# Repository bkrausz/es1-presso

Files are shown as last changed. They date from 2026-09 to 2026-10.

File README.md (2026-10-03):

# Presso

Gravimetric shot control for the **Fellow Espresso Series 1** — without opening the machine.

A small servo sits on top of the Series 1 and taps the espresso key. An ESP32 running
[ESPHome](https://esphome.io) talks to an **Acaia Lunar** over Bluetooth, watches the weight,
and taps the key again when the shot hits your target. It learns the drip offset after each
shot, notices shots you start by hand, and everything is exposed to Home Assistant.

The Series 1 has no scale integration of its own (as of firmware 2.3.x). This gets you
stop-at-weight today, for about $60 in parts, with zero warranty exposure — the mount clamps
to a lip on the case and lifts off in a second.

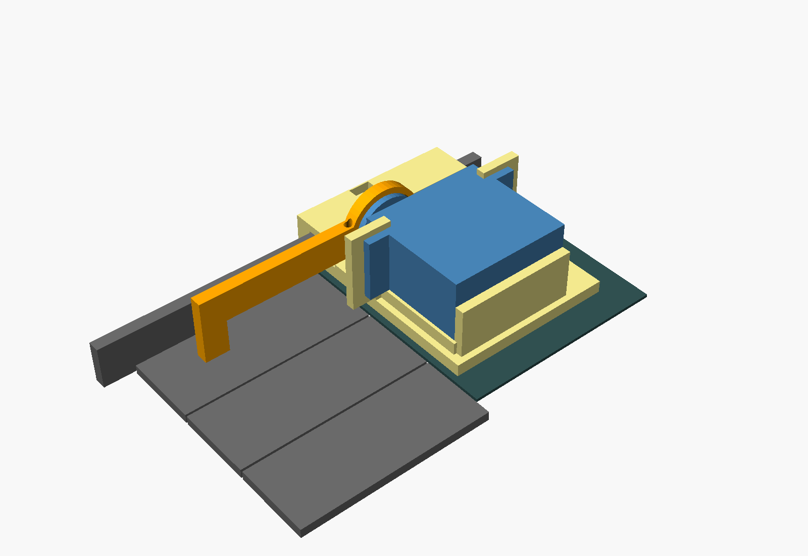
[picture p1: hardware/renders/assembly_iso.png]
Presso mount rendered on the Series 1's key cluster


> **Built with Claude.** The mount, firmware, wiring, and most of this README were designed and
> written by [Claude](https://claude.ai) (Anthropic) in conversation with Brian, who did the
> measuring, soldering, printing, and testing. The Acaia BLE protocol handling is ported from
> Tate Mazer's [AcaiaArduinoBLE / shotStopper](https://github.com/tatemazer/AcaiaArduinoBLE) —
> go star that project.

## How it works

1. You put the cup on the scale (Lunar auto-tare handles zeroing) and press **Pull shot** —
   in Home Assistant or with the button on the Atom.
2. Presso tares, starts the scale timer, and taps the espresso key.
3. It watches weight and flow rate. When `weight + flow × latency ≥ target − offset`, it taps
   the key again. It only ever presses while coffee is still flowing: if the machine ends the shot
   on its own (volumetric target, or you pressed the key), Presso stands down rather than pressing
   into a stopped machine — which would start a *new* shot. "Stopped" only counts once coffee
   has started arriving, so long pre-infusion with a dry cup is fine.
4. Three seconds after the stop it reads the settled weight and nudges the offset by the error,
   so the second or third shot lands on target.

Start the shot by hand instead and Presso notices the weight climbing and takes over the stop.

There's also a bare **Press key** button, which a Home Assistant automation uses to wake the
machine to warm up — guarded by a power-monitoring smart plug so it only presses when the machine
is actually asleep.

## Parts

Prices are rough US retail, Sept 2026.

| Part | Notes | ~$ |
|---|---|---|
| [M5Stack AtomS3 Lite](https://shop.m5stack.com/products/atoms3-lite-esp32s3-dev-kit) | ESP32-S3, BLE + Wi-Fi, 24 mm cube | 8 |
| [M5Stack ATOMIC PROTO Kit](https://shop.m5stack.com/products/atomic-proto-kit) | Perfboard + case that the Atom clips onto | 4 |
| MG996R servo | Metal gear, ~10 kg·cm. Overkill in torque, which is why there's a hard stop | 6 |
| [Adafruit USB Type-C Breakout #4090](https://www.adafruit.com/product/4090) | Has the 5.1 kΩ CC resistors, so a USB-C PD brick gives 5 V/3 A | 3 |
| Anker Nano 20 W USB-C charger | Any 5 V/3 A USB-C brick. Don't power the servo from the Atom's own USB port | 12 |
| Short USB-C to USB-C cable | ≤ 1 m, 60 W-rated is plenty | — |
| 1000 µF 16 V electrolytic capacitor | Across the 5 V rail, soaks up the servo's start-up spike | 1 |
| 3-pin male header + servo extension cable | Header solders to the proto; extension reaches the mount | 3 |
| 22 AWG silicone wire | For the 5 V / GND run to the servo header | — |
| Screws | 4× M3×10 + nuts (servo ears), 1× M4×16 + nut (lip clamp), 1× M3×20 + nut (hard stop), M2 horn screws from the servo bag | 3 |
| ~60 g PLA (or PETG) | Two printed parts | 2 |
| Scrap of TPU or a silicone bumper | Pad on the arm tip; felt inside the lip clamp | — |

Optional:

| Part | Notes |
|---|---|
| Eve Energy (Matter/Thread) or Kasa KP125M | Power-monitoring smart plug on the machine — lets Home Assistant know whether it's asleep, which the wake automation needs |
| Grove-to-Dupont cable | If you'd rather not solder to the proto at all |

## Build

### 1. Print

`hardware/presso_base.stl` and `hardware/presso_arm.stl`. PLA works fine; the working unit is
PLA. PETG is an option if you want extra margin against heat from the warming mat under the base.

- Base: as exported, flat. 4 walls, 30 % infill, no supports.
- Arm: as exported (lying flat, horn pocket up). 5 walls or 100 % infill — it's a 60 mm cantilever taking 300 g.

Everything is parametric in `hardware/presso_mount.scad` (OpenSCAD). The measurements at the top
are from one Series 1; if yours differs, change the numbers and re-export. `lip_slot_clear` and
`key_rear_clear` are the two most likely to need a nudge.

**How the mount sits.** The base rests on the warming mat directly behind the keys. Its outboard
end straddles the raised lip on the side of the machine; an M4 bolt through the outer wall pinches
that lip. That clamp is what stops the whole thing lifting when the servo pushes down — the press
force is larger than the mount weighs. The servo lies on its side on a riser, shaft toward the lip,
body stretching across behind the other two keys. The arm bolts to the round horn and reaches
forward over the espresso key; a pad at the tip lands 18 mm from the key's front edge.

**Hard stop.** An M3 screw threads vertically through the arm near the hub, tip down. At full key
press it touches a landing pad on the base. Set it so the key just bottoms out; the stop, not the
servo, should define the end of travel. The MG996R can crack the fascia if it's ever asked for too
much angle.

### 2. Wire

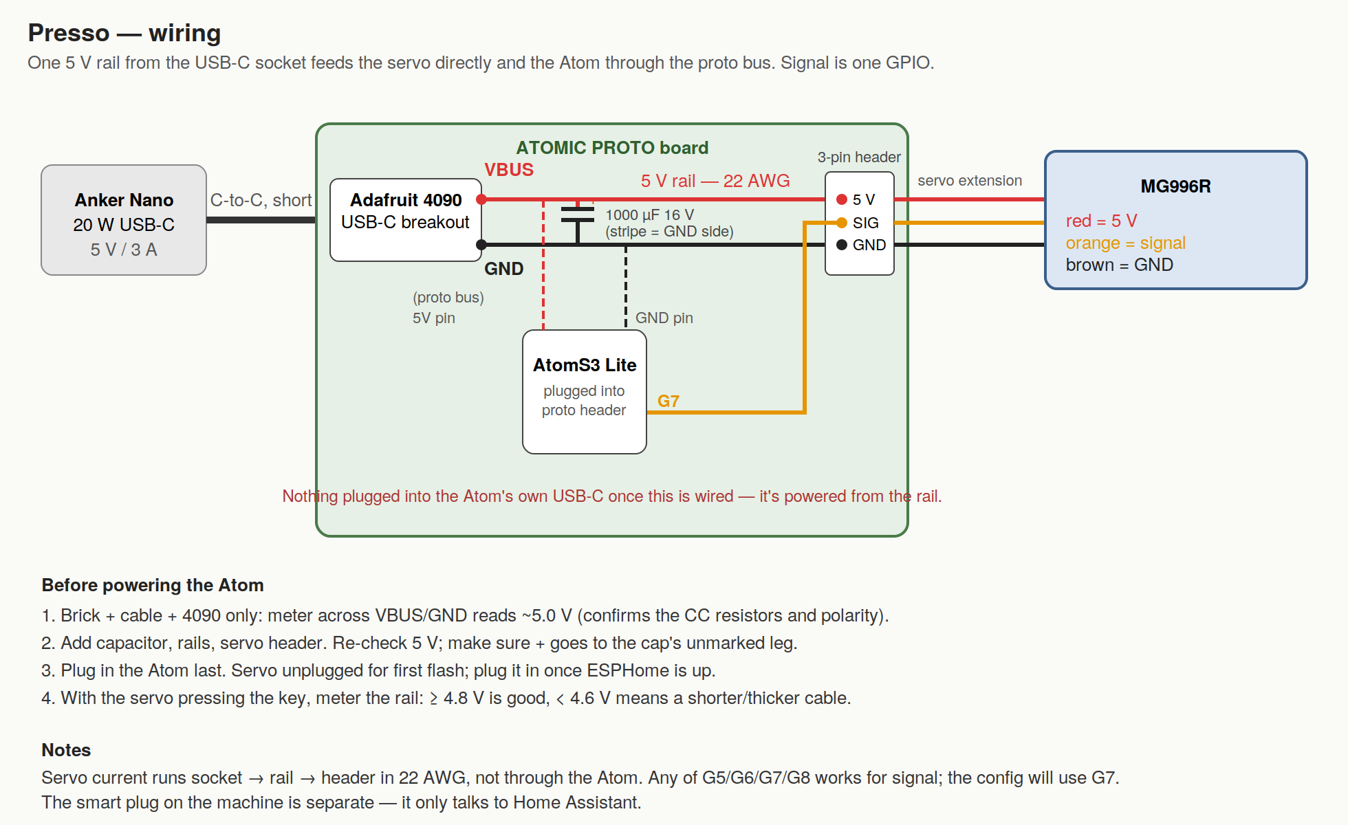
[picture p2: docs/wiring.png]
Wiring


One 5 V rail from the USB-C breakout feeds the servo directly and the Atom through the proto
board's 5V pin. Signal is one GPIO (G7 by default). Seven connections total; the diagram has the
checklist. The two rules: servo current goes through your own 22 AWG wire, not through the Atom's
header pins; and check for ~5 V at the breakout with only the brick attached before soldering
anything else to it.

Notes from the build:
- Leave the breakout's pin header off — you only need VBUS and GND, so solder wires to those two
  pads and hot-glue the board wherever the socket can poke through the case.
- Solder the servo header with the **long** side up. The servo plug's contacts are recessed and
  need the full pin length.
- The Atom's own USB-C port is only for the first flash. After that it's powered from the rail.

### 3. Flash

- Copy `firmware/secrets.example.yaml` to `firmware/secrets.yaml` and fill it in.
- Find your Lunar's Bluetooth address: uncomment the `on_ble_advertise` block in `presso.yaml`,
  flash, turn the scale on, and watch the logs for `name='LUNAR-…'`. (iOS hides BLE addresses,
  so nRF Connect on an iPhone can't tell you.) Put it in `scale_mac`, remove the block, reflash.
- First flash is over USB: hold the Atom's side reset button ~2 s until the LED goes green, then
  install from the ESPHome dashboard. Everything after that is OTA, encrypted with the API key
  (`ota: encryption:`, ESPHome 2026.9 or newer).
- Upgrading a Presso that's running firmware built before ESPHome 2026.9? The uploader refuses
  to send an encrypted-OTA build to a device that can't decrypt it. Comment out the
  `encryption:` line under `ota:`, install once, then restore it and install again.
- **Servo unplugged for the first flash.** Plug it in once ESPHome is running; it's safe to
  hot-plug after that because the firmware detaches the servo at boot and after every press.

### 4. Tune

All of this is done from Home Assistant, with the mount off the machine first.

1. `Servo rest position` moves the servo live. Find rest = arm level.
2. Set `Servo press position` a little past where the pad would bottom the key and hit
   **Press key**. Wrong direction? Flip the sign. The arm only needs ~6°.
3. Mount on the machine with it *asleep* (a press just wakes it). Creep the press position toward
   the key until it registers, set the hard-stop screw to touch at that angle, back the press
   position off a hair past it.
4. Scale on: `Scale connected` should turn on within ~10 s and `Scale weight` should track.
   If it connects but never updates, raise the delay at the top of the `scale_init` script to 3 s.
5. First shot. Watch `Shot state`. Two or three shots and `Stop offset` settles.

### 5. Home Assistant

`homeassistant/automations.yaml` has a template sensor for "machine is awake" (from the smart
plug's power reading), the guarded wake automation, a safety that aborts shot logic if a press
happened while the machine was asleep, and a logbook entry per shot. Swap in your plug's power
entity and your phone's notify service.

## Entities

| | |
|---|---|
| **Buttons** | Pull shot · Press key · Tare scale · Abort shot logic |
| **Numbers** | Target weight · Stop offset · Stop latency · Servo rest / press position · Press hold time · Max shot time |
| **Switches** | Auto-stop manual shots · Learn offset |
| **Sensors** | Scale weight · Flow rate · Shot time · Last shot weight · Shot state · Scale connected · Brewing |

Atom button: tap = Pull shot, hold 1 s = Press key. LED: blue idle, green brewing, dim red = no scale.

## Caveats

- The machine's own volumetric target must be *higher* than your weight target, or the two race
  and the machine wins (Presso then correctly does nothing).
- If you deliberately stop a shot short by hand, turn `Learn offset` off first, or it'll shift the
  offset the wrong way. Errors over 5 g are ignored automatically.
- A servo on a coffee machine is a servo on a coffee machine. Keep the hard stop set, keep the
  clamp snug, and don't leave it unattended with `Auto-stop manual shots` on until you trust it.
- Fellow have said scale integration is on their radar. If they ship it, this repo becomes a
  nice paperweight. Until then.

## Credits

- Acaia BLE protocol: [tatemazer/AcaiaArduinoBLE](https://github.com/tatemazer/AcaiaArduinoBLE)
  (public domain). The identify/heartbeat/notification packets and the weight-packet parsing are
  taken directly from it, and the stop-early-then-learn-the-offset approach is the shotStopper's.
- Design, firmware, and docs: Claude (Anthropic), with Brian Krausz.

## License

MIT — see [LICENSE](LICENSE).

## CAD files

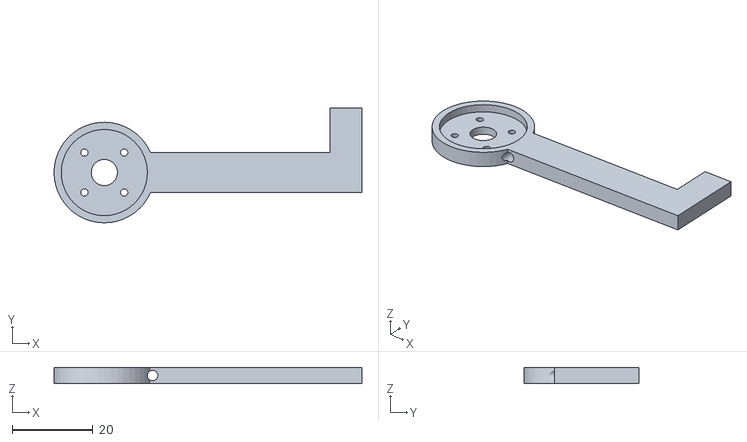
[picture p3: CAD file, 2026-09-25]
hardware/presso_arm.stl
76.5 x 28.5 x 4.00

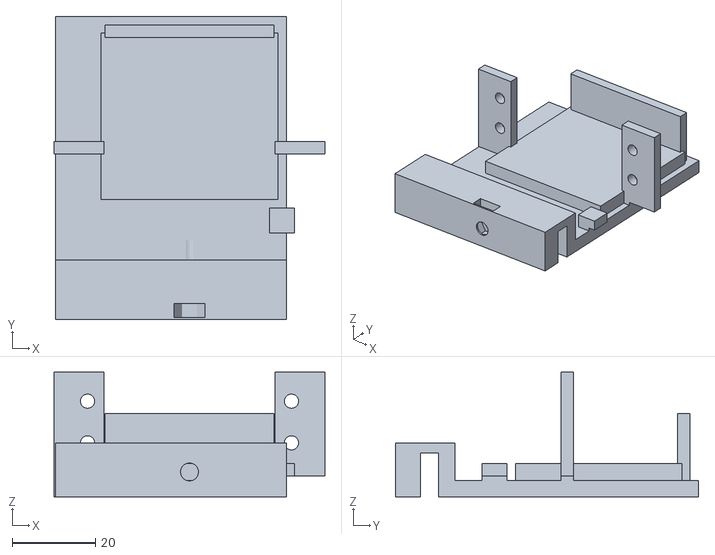
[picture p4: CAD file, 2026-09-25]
hardware/presso_base.stl
65.0 x 72.8 x 30.0

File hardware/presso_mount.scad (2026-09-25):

// ============================================================
//  Fellow Espresso Series 1 — piano-key servo presser (MG996R)
//  Two printed parts: BASE (sits on the warming mat behind the keys,
//  clamps to the raised side lip) and ARM (bolts to the servo horn).
//
//  Coordinates:  X = front/back (+X toward the FRONT of the machine)
//                Y = left/right (0 = inner face of the raised side lip,
//                    +Y across the keys: espresso, steam, hot water)
//                Z = up, Z=0 = top of the warming mat (base sits here)
//  Units: mm.  Everything you might need to tune is in the block below.
// ============================================================

part = "assembly";   // "base" | "arm" | "assembly"   (set via -D on the CLI)

// ---------- machine measurements (yours) ----------
key_len          = 63;     // front-to-back length of a key (pivot at rear)
key_w            = 25;     // width of one key
key_gap          = 0.7;    // gap between keys (you said <1mm)
lip_to_first_key = 1;      // raised side lip -> hot-water key
lip_thick        = 4;      // raised side lip thickness
lip_above_key    = 11;     // lip height above key top
mat_above_key    = 1;      // warming mat sits ~1mm above key top
key_travel       = 3;      // key front dips this much for a press
press_from_front = 18;     // where the pad lands, measured from key FRONT edge

// ---------- clearances / tuning ----------
key_rear_clear   = 2;      // base front edge sits this far behind the key rear
rest_clear       = 3;      // pad bottom above key at rest
overtravel       = 0.5;    // extra beyond full key travel the stop allows
lip_slot_clear   = 0.3;    // slot = lip_thick + this   (tighten if it rocks)
sv_riser         = 4;      // servo sits this high off the plate (lets the arm hub clear it)

// ---------- MG996R (standard-size servo footprint; check with calipers) ----------
sv_len      = 40.5;   // body length (ear direction)
sv_w        = 20.0;   // body width
sv_h        = 38.0;   // body bottom -> top of case (shaft face)
sv_ear_z    = 28.0;   // bottom -> underside of ears
sv_ear_t    = 2.5;    // ear thickness
sv_ear_ext  = 7.0;    // ears stick out past each body end
sv_hole_dx  = 49.0;   // hole spacing along length
sv_hole_dy  = 10.0;   // hole spacing across width
sv_hole_d   = 3.4;    // M3 clearance (ear holes are ~4mm)
sv_shaft_off= 10.0;   // shaft center from the shaft-end of the body
sv_horn_h   = 4.0;    // case top -> underside of the horn disc

// ---------- horn disc (measure the round horn in your MG996R bag) ----------
horn_d      = 21.0;   // round horn diameter
horn_t      = 2.0;    // horn thickness
horn_bc_r   = 7.0;    // radius of the 4 screw holes on the horn
horn_screw_d= 1.8;    // self-tap hole for the M2 horn screws
horn_center_d = 6.5;  // clearance for the center retaining-screw head

// ---------- printed part sizes ----------
base_t      = 4;      // base plate thickness
wall        = 3;      // general wall thickness
arm_t       = 4;      // arm thickness (lateral)
arm_h       = 10;     // arm beam height
pad_w       = 8;      // pad footprint front/back
stop_screw_d= 2.6;    // M3 self-tap hole for the adjustable stop screw

$fn = 48;

// ============================================================
//  Derived geometry
// ============================================================
key_pitch   = key_w + key_gap;
esp_y0      = lip_to_first_key;                 // espresso key is the one next to the lip
esp_yc      = esp_y0 + key_w/2;                 // espresso key centerline
key_top_z   = -mat_above_key;                   // key surface (mat = 0)
lip_top_z   = key_top_z + lip_above_key;

// servo lies on its side: shaft axis along +Y, body bottom face at sv_y0
arm_yc      = esp_yc;                             // arm plane on key centerline
sv_ytop     = arm_yc + arm_t/2 + sv_horn_h;       // shaft face of the case (faces the lip)
sv_ybot     = sv_ytop + sv_h;                     // bottom face of the case (away from lip)
ear_y1      = sv_ybot - sv_ear_z;                 // ear plate, shaft-side face
ear_y0      = ear_y1 - sv_ear_t;
tab_y0      = ear_y1;                             // tab sits on the BODY side of the ear (ear between tab and horn)
tab_y1      = tab_y0 + wall;

sv_xfront   = -key_rear_clear - wall;             // shaft-end of body
sv_xback    = sv_xfront - sv_len;
shaft_x     = sv_xfront - sv_shaft_off;
shaft_z     = base_t + sv_riser + sv_w/2;
body_xc     = (sv_xfront + sv_xback)/2;

press_x     = key_len - press_from_front;         // pad lands here (X)
arm_L       = press_x - shaft_x;                  // shaft -> pad, horizontal
press_dip   = key_travel * press_x / key_len;     // key dips this much at pad
press_angle = asin((rest_clear + press_dip + overtravel) / arm_L);

base_x0     = sv_xback - sv_ear_ext - wall - 2;   // rear edge of base
base_x1     = -key_rear_clear;                    // front edge of base
base_y0     = -(lip_thick + lip_slot_clear) - 6;  // outboard wall of lip clamp
base_y1     = sv_ybot + wall + 2;                 // just past the servo fence

stop_x      = base_x1 - 1;                        // stop screw in the arm lands on plate here
hub_r       = horn_d/2 + 2;                       // arm hub radius
stop_pad_z  = 8;                                  // landing pad height for the stop screw

echo(str("arm length shaft->pad = ", arm_L, " mm"));
echo(str("press angle (rest -> full press) = ", press_angle, " deg"));
echo(str("key dip at pad = ", press_dip, " mm"));
echo(str("hub lowest point above plate top = ", (shaft_z - hub_r) - base_t, " mm"));
echo(str("stop screw tip below arm beam at full press = ", (shaft_z - arm_h/2) - stop_pad_z - (stop_x - shaft_x) * sin(press_angle), " mm"));

// ============================================================
//  BASE
// ============================================================
module base() {
    difference() {
        union() {
            // plate
            translate([base_x0, base_y0, 0])
                cube([base_x1 - base_x0, base_y1 - base_y0, base_t]);

            // lip clamp block (straddles the raised side lip)
            translate([base_x0, base_y0, 0])
                cube([base_x1 - base_x0, -base_y0 + 4, lip_top_z + wall]);

            // riser pad under the servo
            translate([sv_xback - 1, sv_ytop - 1, 0])
                cube([sv_len + 2, sv_h + 2, base_t + sv_riser]);

            // fence at the servo's bottom face (keeps body from sliding away from the lip)
            translate([sv_xback, sv_ybot, 0])
                cube([sv_len, wall, base_t + sv_riser + 12]);

            // ear tabs (front and rear), plates in XZ on the body side of the ears
            // inner faces must clear the servo body (gap = sv_len + 0.6)
            for (sgn = [1, -1]) {
                xc = body_xc + sgn * sv_hole_dx/2;
                x_in  = body_xc + sgn * (sv_len/2 + 0.3);   // inner face
                x_out = xc + sgn * 8;                         // outer face
                translate([min(x_in, x_out), tab_y0, 0])
                    cube([abs(x_out - x_in), wall, base_t + sv_riser + sv_w + 2]);
            }

            // landing pad for the arm's stop screw
            translate([stop_x - 3, arm_yc - 3, 0])
                cube([6, 6, stop_pad_z]);

        }

        // slot for the raised lip (open at the bottom)
        translate([base_x0 - 1, -(lip_thick + lip_slot_clear), -1])
            cube([base_x1 - base_x0 + 2, lip_thick + lip_slot_clear, lip_top_z - mat_above_key + 0.5 + 1 + mat_above_key]);

        // clamp screw (M4) through the outboard wall, with nut trap
        translate([body_xc, base_y0 - 1, (lip_top_z)/2 + 1])
            rotate([-90, 0, 0]) {
                cylinder(d = 4.3, h = 20);
                // hex nut slot, open to the top of the block
                translate([0, 0, 1.5]) hull() {
                    cylinder(d = 7.4, h = 3.4, $fn = 6);
                    translate([0, -20, 0]) cylinder(d = 7.4, h = 3.4, $fn = 6);
                }
            }

        // ear screw holes (M3), through the tabs along Y
        for (xc = [body_xc + sv_hole_dx/2, body_xc - sv_hole_dx/2])
            for (dz = [-sv_hole_dy/2, sv_hole_dy/2])
                translate([xc, tab_y0 - 1, shaft_z + dz])
                    rotate([-90, 0, 0]) cylinder(d = sv_hole_d, h = wall + 2);

        // nothing may hang over the keys lower than 6mm above them
        translate([base_x1, -20, -20])
            cube([100, 200, 20 + key_top_z + 6]);

    }
}
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

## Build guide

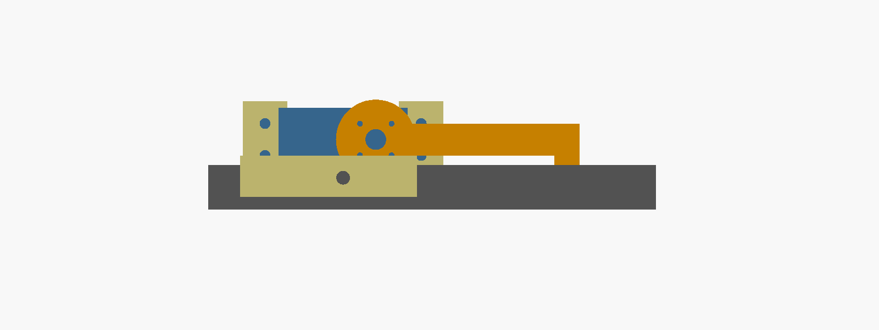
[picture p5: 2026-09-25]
hardware/renders/assembly_side.png

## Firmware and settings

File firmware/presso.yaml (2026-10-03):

# ============================================================
#  Presso — gravimetric key presser for the Fellow Espresso Series 1
#  AtomS3 Lite + MG996R + Acaia Lunar (2021, "new" BLE protocol)
#
#  What it does
#   - Connects to the Lunar over BLE, keeps it alive with heartbeats,
#     streams weight at ~10 Hz.
#   - "Pull shot": tares, presses the espresso key, watches weight + flow,
#     presses again just before target - offset is reached, then measures
#     the settled weight 3 s later and learns the drip offset for next time.
#   - Also notices shots you start by hand (weight starts climbing) and
#     takes over the stop.
#   - "Press key" / "Wake machine": one bare press for HA automations.
#
#  Things to fill in: substitutions below (scale MAC, wifi secrets).
# ============================================================

substitutions:
  name: presso
  friendly_name: "Presso"
  scale_mac: "AA:BB:CC:DD:EE:FF"      # <-- your Lunar's BLE address (see README)
  servo_pin: GPIO7                    # signal wire; any of G5/G6/G7/G8 on the AtomS3 Lite
  # Acaia "new" protocol (Lunar 2021, Pyxis, Pearl S)
  acaia_service: 49535343-fe7d-4ae5-8fa9-9fafd205e455
  acaia_write:   49535343-8841-43f4-a8d4-ecbe34729bb3
  acaia_notify:  49535343-1e4d-4bd9-ba61-23c647249616

esphome:
  name: ${name}
  friendly_name: ${friendly_name}
  on_boot:
    priority: -100
    then:
      - servo.detach: key_servo
      - light.turn_on: { id: status_led, red: 0, green: 0, blue: 0.3, brightness: 0.4 }

esp32:
  board: m5stack-atoms3
  variant: esp32s3
  framework:
    type: esp-idf

logger:
  level: INFO

api:
  encryption:
    key: !secret api_key

captive_portal:

# OTA uploads are encrypted and authenticated with the same key as the API
# (needs ESPHome 2026.9+). No separate OTA password.
ota:
  - platform: esphome
    encryption:

wifi:
  ssid: !secret wifi_ssid
  password: !secret wifi_password
  ap:
    ssid: "${friendly_name} Setup"

# ------------------------------------------------------------
#  BLE — Acaia Lunar
# ------------------------------------------------------------
esp32_ble_tracker:
  scan_parameters:
    active: true
  # To find your scale's address the first time, uncomment this, flash, and
  # watch the logs for a line with name='LUNAR-...'. Remove it afterwards.
  # on_ble_advertise:
  #   - then:
  #       - lambda: |-
  #           ESP_LOGI("ble", "%s  rssi=%d  name='%s'",
  #                    x.address_str().c_str(), x.get_rssi(), x.get_name().c_str());

ble_client:
  - mac_address: ${scale_mac}
    id: lunar
    auto_connect: true
    on_connect:
      then:
        - lambda: 'id(scale_connected) = true;'
        - script.execute: scale_init
    on_disconnect:
      then:
        - lambda: |-
            id(scale_connected) = false;
            id(scale_weight).publish_state(NAN);

# ------------------------------------------------------------
#  Servo
# ------------------------------------------------------------
output:
  - platform: ledc
    pin: ${servo_pin}
    id: servo_pwm
    frequency: 50 Hz

servo:
  - id: key_servo
    output: servo_pwm
    auto_detach_time: 0s
    transition_length: 0s
    min_level: 3%      # 0.6 ms pulse
    max_level: 12%     # 2.4 ms pulse

# ------------------------------------------------------------
#  Status LED (AtomS3 Lite: WS2812 on GPIO35)
# ------------------------------------------------------------
light:
  - platform: esp32_rmt_led_strip
    id: status_led
    pin: GPIO35
    chipset: WS2812
    num_leds: 1
    channel_colors: GRB
    name: "Status LED"
    internal: true

# ------------------------------------------------------------
#  State
# ------------------------------------------------------------
globals:
  - id: scale_connected
    type: bool
    initial_value: 'false'
  - id: brewing
    type: bool
    initial_value: 'false'
  - id: we_started
    type: bool
    initial_value: 'false'
  - id: shot_start_ms
    type: uint32_t
    initial_value: '0'
  - id: shot_end_ms
    type: uint32_t
    initial_value: '0'
  - id: flow_gps
    type: float
    initial_value: '0'
  - id: inst_flow
    type: float
    initial_value: '0'
  - id: last_w
    type: float
    initial_value: '0'
  - id: last_w_ms
    type: uint32_t
    initial_value: '0'
  - id: rising_samples
    type: int
    initial_value: '0'
  - id: flow_started
    type: bool
    initial_value: 'false'
  - id: stall_since_ms
    type: uint32_t
    initial_value: '0'
  - id: awaiting_final
    type: bool
    initial_value: 'false'
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

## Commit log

2026-09-25 Presso: gravimetric key presser for the Fellow Espresso Series 1
    Servo mount (OpenSCAD + STLs), ESPHome firmware with Acaia Lunar BLE
    support, wiring diagram, Home Assistant automations, and build guide.
    Claude-Session: https://claude.ai/code/session_01THiDMGJzAFpesmqNam6tbY
    [presso_arm.stl, presso_base.stl, presso_mount.scad]
2026-09-25 README: PLA is fine for the printed parts
    Claude-Session: https://claude.ai/code/session_01NE2zyr6Zh7wYeZRuKATwX2
2026-09-27 Don't give up on shots during long pre-infusion
    The "machine stopped by itself" check fired on any 2.5 s of no flow after
    8 s, so a pre-infusion that kept the cup dry for ~10 s ended the shot
    logic (and stopped the scale timer) before the first drip. Only treat
    low flow as a stop once coffee has actually started arriving.
    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
2026-10-03 Encrypt OTA with the API key; use channel_colors for the status LED
    ota: encryption: (ESPHome 2026.9+) reuses the api key, so uploads are
    encrypted and authenticated without a separate password. Previously OTA
    had neither. rgb_order is deprecated in favour of channel_colors.
    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
